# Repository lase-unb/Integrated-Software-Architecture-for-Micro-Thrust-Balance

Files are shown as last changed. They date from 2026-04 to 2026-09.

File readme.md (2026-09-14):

# Integrated Software Architecture for Micro-Thrust Balance

> Pipeline digital de quatro camadas para automação metrológica e tratamento de ruídos em bancadas de microempuxo 





---

## Visão Geral

Este repositório contém a arquitetura de software desenvolvida no **Laboratório de Sistemas Espaciais (LaSE)** da Universidade de Brasília (UnB) para caracterização precisa de sistemas de micropropulsão.

A arquitetura é estruturada em um **pipeline digital de quatro camadas** implementado em Python, integrando análise espectral (FFT), filtragem Butterworth de quinta ordem com fase zero, Filtro de Kalman sintonizado em Gêmeo Digital, gerenciamento metrológico de dados e interface Streamlit para telemetria e geração automatizada de relatórios PDF institucionais.

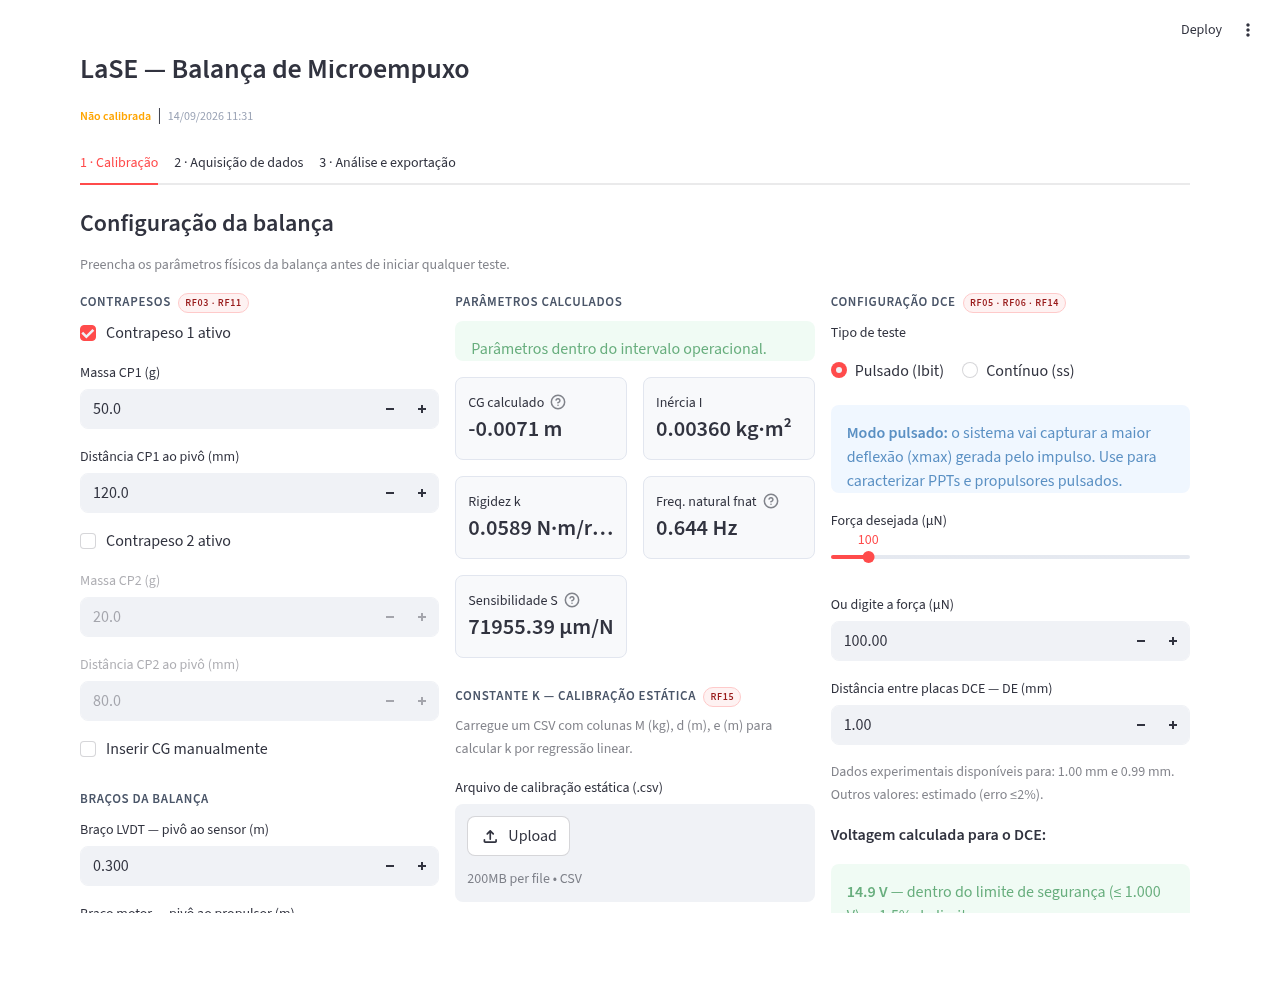
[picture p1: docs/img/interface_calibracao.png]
Aba de calibração da interface Streamlit


---

## Estrutura do Repositório

```
Integrated-Software-Architecture-for-Micro-Thrust-Balance/
│
├── Análises/                        # Análises experimentais anteriores (LaSE)
│   ├── data/                        # Dados brutos dos experimentos
│   ├── resultados/                  # Resultados processados
│   └── src/
│       ├── Hector/                  # Scripts de análise (H. Gessini)
│       └── ...                      # Scripts de análise física
│
├── calibration/                     # Camada 3 — calibração e gerenciamento
│   ├── physics/                     # Modelos físicos da balança
│   │   ├── centro_gravidade.m       # Cálculo do centro de gravidade
│   │   ├── carga_constante.m        # Análise de carga constante
│   │   ├── carga_constante_derivaTermica.m
│   │   ├── efeitojoule.py           # Modelagem efeito Joule
│   │   ├── efeitojoule_2.py
│   │   ├── eletroima_forca.py       # Força eletromagnética
│   │   ├── forca_eletroima.m
│   │   ├── graph_calibracao.m
│   │   ├── movimento_nucleo.py      # Dinâmica do núcleo
│   │   ├── plot_carga_cte.m
│   │   ├── relatorio_calibracao.py
│   │   ├── restricao_geo_forca.py
│   │   ├── superficie_calibracao.m
│   │   ├── 2_modo_vibracao.py       # Análise de modos de vibração
│   │   └── calibracao.py
│   ├── find_deflection.py           # Análise de deflexão + incerteza GUM (importado por interface/main.py)
│   ├── k_calculation.py             # Constante de rigidez efetiva k (importado por interface/main.py)
│   ├── dce_calibration.py           # Calibração in situ via DCE (simulada, sem hardware validado)
│   └── pendulum-dynamic.py          # Modelo dinâmico do pêndulo
│
├── signal_processing/               # Camadas 1 e 2 — FFT + DSP
│   ├── fn_calculation.py            # Análise espectral FFT + detecção de fn (importado por interface/main.py)
│   ├── processing.py                # Filtro Butterworth 5ª ordem + Kalman + conversão µm→mN
│   └── simulator.py                 # Gêmeo Digital do sistema dinâmico
│
├── interface/                       # Camada 4 — interface e relatórios
│   ├── main.py                      # Aplicação Streamlit (entry point — abas de calibração, aquisição e análise/exportação)
│   ├── live_plot.py                 # Telemetria em tempo real (50 ms)
│   ├── report_pdf.py                # Gerador de relatório PDF bilíngue PT/EN
│   └── web/                         # Interface web alternativa (HTML/CSS)
│       ├── index.html               # Dashboard
│       ├── calibracao.html          # Página de calibração
│       ├── analise.html             # Análise e exportação
│       └── style.css
│
├── hardware/                        # Aquisição de dados
│   ├── data_acquisition.py          # Interface serial USB com LVDT
│   └── dce_power_supply.py          # Driver SCPI/USB da fonte do DCE (real + simulado)
│
├── tools/                           # Scripts auxiliares
│   └── LVDT_Plot_V2.py              # Identificação de deslocamento máximo (importado por interface/main.py)
│
├── docs/                            # Documentação técnica
│   └── balanca.md                   # Especificações da balança
│
├── requirements.txt                 # Dependências Python
├── .gitignore
└── README.md
```

---

## Instalação

### Pré-requisitos

- Python 3.9+
- pip

### Passos

```bash
# Clone o repositório
git clone https://github.com/lase-unb/Integrated-Software-Architecture-for-Micro-Thrust-Balance.git
cd Integrated-Software-Architecture-for-Micro-Thrust-Balance

# Instale as dependências
pip install -r requirements.txt

# Execute a interface principal
streamlit run interface/main.py
```

---

## Pipeline de Quatro Camadas

| Camada | Módulo | Função |
|---|---|---|
| 1 — Análise Espectral | `signal_processing/fn_calculation.py` | FFT + janela Hanning → identificação de fn |
| 2 — DSP | `signal_processing/processing.py` | Butterworth 5ª ordem + filtfilt + Kalman |
| 2 — Gêmeo Digital | `signal_processing/simulator.py` | Modelo dinâmico para sintonização do Kalman |
| 3 — Calibração | `calibration/k_calculation.py` | Constante k, ajuste linear, R² |
| 3 — Metrologia | `calibration/find_deflection.py` | Deflexão + incerteza σ_d (GUM) |
| 3 — Pico de deflexão | `tools/LVDT_Plot_V2.py` | Identificação de xmax (regime pulsado) |
| 4 — Interface | `interface/main.py` | Streamlit: calibração, aquisição, análise (3 abas) |
| 4 — Telemetria | `interface/live_plot.py` | Monitoramento tempo real (50 ms) |
| 4 — Relatório | `interface/report_pdf.py` | PDF institucional bilíngue PT/EN, via ReportLab |

Os módulos das Camadas 1–3 (`fn_calculation.py`, `find_deflection.py`, `k_calculation.py`, `LVDT_Plot_V2.py`) funcionam tanto de forma independente (`python <script>.py`, para análise offline de um arquivo) quanto importados diretamente por `interface/main.py` — não há lógica duplicada entre o app e os scripts standalone.

---

## Guia de Módulos

Descrição do que cada arquivo da arquitetura faz e como ele se encaixa no pipeline. Não cobre `Análises/` (scripts históricos de experimentos anteriores do LaSE, fora da arquitetura de software mantida).

### `calibration/`

`find_deflection.py` calcula a deflexão (Δd) entre uma janela de baseline e uma janela de patamar, com incerteza combinada σ_c = √(σ₁²+σ₂²) (GUM). A função `calcular_deflexao()` é importada por `interface/main.py`, mas o script também roda sozinho (`python find_deflection.py arquivo.txt`) para uma análise offline com gráfico.

Rigidez efetiva k é assunto de dois módulos, dependendo da fonte de força usada na calibração. `k_calculation.py` faz isso a partir de massas conhecidas — regressão linear T(θ)=k·θ+a por mínimos quadrados, com R² pra validar o ajuste (`calibracao_estatica()`). `dce_calibration.py` faz o mesmo ajuste, mas trocando a massa pela força eletrostática do DCE (lei quadrática de placas paralelas, `forca_dce()`), varrendo voltagens e lendo a deflexão resultante em `calibrar_via_dce()`. Tem interlock de 1000V embutido, mas **só foi validado em simulação** até agora (`python dce_calibration.py`, com `FontePowerSupplySimulada`) — falta testar com a fonte/DCE/LVDT reais e ligar isso na interface Streamlit.

`pendulum-dynamic.py` ainda não tem implementação — só cabeçalho, reservado pras equações diferenciais da dinâmica do pêndulo (simples e 2º modo de vibração). E `physics/` guarda os scripts MATLAB/Python de modelagem física usados no dimensionamento da balança (efeito Joule, força eletromagnética, geometria do núcleo); não são importados pelo app, ficam como referência de cálculo.

### `signal_processing/`

`processing.py` é o núcleo de DSP do projeto e é importado por praticamente todo o resto (main.py, live_plot.py, fn_calculation.py, LVDT_Plot_V2.py). `apply_kalman_filter()` implementa o Filtro de Kalman linear de 2 estados (posição e velocidade) sintonizado pela frequência natural; `apply_lowpass_filter()` roda o Butterworth 5ª ordem fase-zero (`filtfilt`) seguido do Kalman; `convert_to_mn()` converte µm em mN; `calculate_metrics()` extrai bias, empuxo nominal e ruído RMS.

A frequência natural (fnat) sai de `fn_calculation.py`, via FFT (rfft) do sinal filtrado buscando o pico de maior magnitude — `calcular_fnat()`, importada por `interface/main.py` e também executável sozinha.

`simulator.py` é diferente dos outros: gera dados sintéticos de pêndulo amortecido (ruído + oscilação + degrau de empuxo) e escreve continuamente em `data.txt` respeitando o tempo real (`time.sleep`), pra testar `live_plot.py` sem hardware. Ninguém importa esse arquivo — `main.py` tem seu próprio gerador de simulação, em lote.

### `interface/`

`main.py` é o ponto de entrada da aplicação (`streamlit run interface/main.py`), com três abas: Calibração, Aquisição de dados e Análise/exportação. `report_pdf.py` gera o relatório PDF bilíngue PT/EN via ReportLab quando o botão "Gerar PDF" da aba 3 é clicado (`gerar_pdf()`). `live_plot.py` é uma ferramenta à parte — visualizador desktop standalone (matplotlib `FuncAnimation`, 50 ms) que lê um arquivo fixo via polling, não integrado ao app Streamlit. E `web/` é só um mockup estático em HTML/CSS/Chart.js, sem backend nenhum por trás.

### `hardware/`

`data_acquisition.py` lê a porta serial USB do condicionador do LVDT (baud rate 9600) e grava em `data.txt` no formato esperado pelos outros módulos. `dce_power_supply.py` é o par de classes usadas pela calibração via DCE: `RigolDP932U` fala SCPI de verdade com a fonte via PyVISA (não testada com hardware ainda), e `FontePowerSupplySimulada` imita a mesma interface sem precisar do equipamento.

### `tools/`

`LVDT_Plot_V2.py` identifica o xmax (maior deflexão absoluta) num sinal já filtrado — usado na análise do regime pulsado, exposto como `detectar_xmax()` e importado por `interface/main.py`.

---

## Publicação

**Arquitetura de Software Integrada para Automação Metrológica e Tratamento de Ruídos em Bancadas de Microempuxo**

Sessão 2 — Sustentabilidade, Educação, Ciência e Tecnologia | Formato: Presencial

**Autores:**
- Luana Carvalho de Almeida — 242004840@aluno.unb.br (UnB)
- Thamiris Thomazini Libard — 200043820@aluno.unb.br (UnB)
- Lui Txai Calvoso Habl — lui.habl@unb.br (UnB)
- Paolo Gessini (UnB)

**Palavras-chave:** micropropulsão · arquitetura de software modular · processamento digital de sinais · calibração eletrostática in situ · Gêmeo Digital

---

## Licença

[PolyForm Noncommercial 1.0.0](LICENSE) — uso, cópia, modificação e redistribuição livres para fins não comerciais (pesquisa, ensino, uso pessoal, organizações sem fins lucrativos). Uso comercial requer licenciamento separado com o LaSE.

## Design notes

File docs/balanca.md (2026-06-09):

<div align="center">

<br/>

**Micro-Thrust Balance — Signal Processing & Autonomous Calibration Pipeline**

*LaSE · Laboratory of Space Systems*

<br/>



[]()
[]()


<br/>

> A full signal processing, autonomous calibration, and data acquisition pipeline  
> for the micro-thrust balance used in small satellite propulsion testing at LaSE.

<br/>

---

</div>

## Overview

This repository contains the software infrastructure for operating the **LaSE Micro-Thrust Balance**, a precision torsional pendulum instrument used to characterize pulsed and continuous thrust from small satellite propulsion systems (PPTs and similar).

The pipeline covers three main layers:

- **Signal Filtering** — real-time noise filtering on LVDT sensor data
- **Autonomous Calibration** — automated static and dynamic calibration sequences (DCE-driven)
- **Interface** — web-based GUI for lab operators, designed for non-specialist use in isolated environments

All modules operate **100% offline** — no internet dependency at runtime — targeting deployment in vacuum chamber environments.

<br/>

---

## Repository Structure

```
microthrustpy/
│
├── filters/                   # Signal processing & noise filtering
│   ├── butterworth.py         #   Butterworth filter (order 5, cutoff 0.05·fnat)
│   ├── fft_analysis.py        #   FFT with Hanning window, 0.01 Hz resolution
│   └── steady_state.py        #   Steady-state detection (<0.1% variation threshold)
│
├── calibration/               # Autonomous calibration pipeline
│   ├── static_cal.py          #   Static calibration sequence
│   ├── dynamic_cal.py         #   Dynamic calibration (J, k, ω₀, S via FFT)
│   ├── dce_controller.py      #   DCE voltage control (<5 ms latency, ≤1000 V limit)
│   └── cg_calculator.py       #   Center-of-gravity computation from counterweight data
│
├── acquisition/               # Data acquisition
│   └── lvdt_reader.py         #   Real-time LVDT capture at 100 Hz (zero-packet-loss)
│
├── analysis/                  # Post-acquisition analysis
│   ├── pulsed_mode.py         #   xmax extraction from transient (first peak-valley)
│   ├── continuous_mode.py     #   Steady-state mean: xss/FE → sensitivity S
│   └── regression.py         #   Linear / least-squares curve fitting (R² > 0.99)
│
├── interface/                 # Web GUI (offline)
│   ├── app.py                 #   Main application entry point
│   ├── pages/                 #   Calibration, Acquisition, Analysis views
│   └── components/            #   Reusable UI components
│
├── reports/                   # Export engine
│   └── exporter.py            #   CSV (UTF-8) and PDF (ReportLab) generation
│
├── docs/                      # Documentation
│   └── requirements_spec.pdf  #   Full software requirements specification
│
├── tests/                     # Unit and integration tests
└── README.md
```

<br/>

---

## Key Features

### Signal Filtering
- Real-time noise reduction on LVDT displacement signals
- Butterworth low-pass filter (order 5, cutoff = `0.05 × fnat`)
- FFT analysis with Hanning window at 0.01 Hz resolution
- Automatic steady-state detection (variation threshold < 0.1%)
- Dashboard updates every **10 ms**; FFT processing < **1 s** for 1-minute signals

### Autonomous Calibration
- Full static + dynamic calibration sequences in < 30 min
- Computes: moment of inertia **J**, torsional stiffness **k**, natural frequency **ω₀**, and sensitivity **S**
- DCE voltage auto-calculation from target force input (precision: 0.1 V)
- Center-of-gravity computation from counterweight mass and position inputs
- Hard voltage limit: **≤ 1000 V** with software interlock, visual/audio alert, and incident logging
- Post-calibration recommendations based on threshold rules (e.g., hysteresis > 2%)

### Acquisition & Analysis
| Mode | Focus | Key Metric |
|---|---|---|
| **Pulsed (DCE)** | Transient regime | `xmax` — first peak-valley, resolution 0.01 μm |
| **Continuous (DCE)** | Steady-state regime | `xss` — mean after τ × 4 settling, σ < 0.01 μm |

- Supports N ≥ 10 repeated pulses with mean and standard deviation
- `xss / FE` → sensitivity S (μm/N or V/N), error < 1% vs. analytical
- FE lookup table from experimental curves; DE interpolation error ≤ 2%

### Interface
- Offline web application (no internet dependency)
- Pulsed / Continuous mode toggle with automatic parameter switching
- Real-time interactive plots (time domain + FFT) with zoom and pan
- Drag-and-drop layout, contextual tooltips, responsive in < 50 ms
- Automatic recalibration alert when mass or CG changes > 1%

### Reporting
- Export to **PDF** (ReportLab) and **CSV** (UTF-8)
- Includes: time/FFT graphs, calibration curves, parameter tables, uncertainty estimates, timestamps
- Download time < 10 s for 1 hour of data

<br/>

---

## Requirements

| Requirement | Value |
|---|---|
| Python | ≥ 3.10 |
| Network | Not required (fully offline) |
| Calibration error | < 1% (INMETRO/EURAMET standards) |
| Measurement repeatability | < 0.05 Ns |
| DCE control latency | < 5 ms |
| Dashboard refresh | 10 ms |
| Max DCE voltage | 1000 V (hard limit) |
| MTBF | ≥ 99.9% over 8 h operation |

<br/>

---

## Getting Started

```bash
# Clone the repository
git clone https://github.com/your-org/microthrustpy.git
cd microthrustpy

# Install dependencies
pip install -r requirements.txt

# Run the interface
python interface/app.py
```

> **Note:** The system is designed for isolated lab environments. No external network calls are made at any point during operation.

<br/>

---

## Requirements Specification

The full software requirements document is available at [`docs/requirements_spec.pdf`](docs/requirements_spec.pdf).

A summary of the requirement matrix:

| ID | Title | Priority | Status |
|----|---|---|---|
| RNF01 | Offline Operation | Must Have | Proposed |
| RF01 | Full Calibration, Acquisition & Analysis Coverage | Must Have | Proposed |
| RF02 | Statistics for Pulsed and Continuous Loads | Must Have | Proposed |
| RF03 | Counterweight & Distance Input for Calibration | Must Have | Proposed |
| RF05 | DCE Force Magnitude Input | Must Have | Proposed |
| RF06 | Automatic DCE Voltage Calculation | Must Have | Proposed |
| RF07 | Steady-State Acquisition (Continuous DCE) | Must Have | Proposed |
| RF08 | Peak Amplitude Analysis (Pulsed DCE) | Must Have | Proposed |
| RF09 | Known-Input Consideration (Continuous DCE) | Must Have | Proposed |
| RF10 | Real-Time Curve Generation | Must Have | Proposed |
| RF13 | Real-Time LVDT Acquisition | Must Have | Proposed |
| RF14 | DCE Voltage Safety Limit (≤ 1000 V) | Must Have | Proposed |
| RF15 | Automated Static/Dynamic Calibration Sequences | Must Have | Proposed |
| RNF02 | Real-Time Performance | Must Have | Proposed |
| RI01 | Time Domain + FFT Visualization | Should Have | Proposed |
| RF16 | CSV/PDF Report Export | Should Have | Proposed |
| RNF03 | Measurement Precision & Reliability | Should Have | Proposed |
| RI02 | Pulsed / Continuous Mode Selection | Must Have | Proposed |
| RF04 | Post-Calibration Recommendations | Could Have | Proposed |
| RF11 | Automatic Center-of-Gravity Calculation | Could Have | Proposed |
| RF12 | Recalibration Reminder on Mass/CG Change | Could Have | Proposed |

<br/>

---

## Instrument Context

The **LaSE Micro-Thrust Balance** is a torsional pendulum designed to measure thrust forces in the range of **10 μN – 1 mN**, used for characterizing pulsed plasma thrusters (PPTs) and similar low-thrust propulsion systems for small satellites.

Key physical parameters:
- Sensor: **LVDT** (Linear Variable Differential Transformer)
- Excitation: **DCE** (Dynamic Capacitive Excitation), U ≤ 1000 V
- Calibration modes: static (sensitivity S) and dynamic (natural frequency ω₀)
- Operating environment: vacuum chamber (isolated, no network)

<br/>

---

## Contributing

This project is developed within the LaSE research group. For contribution guidelines, please refer to [`CONTRIBUTING.md`](CONTRIBUTING.md).

<br/>

---

## License

MIT License — see [`LICENSE`](LICENSE) for details.

<br/>

<div align="center">

---

*LaSE · Laboratory of Space Systems*  
*Developed for the Micro-Thrust Balance Project*

</div>

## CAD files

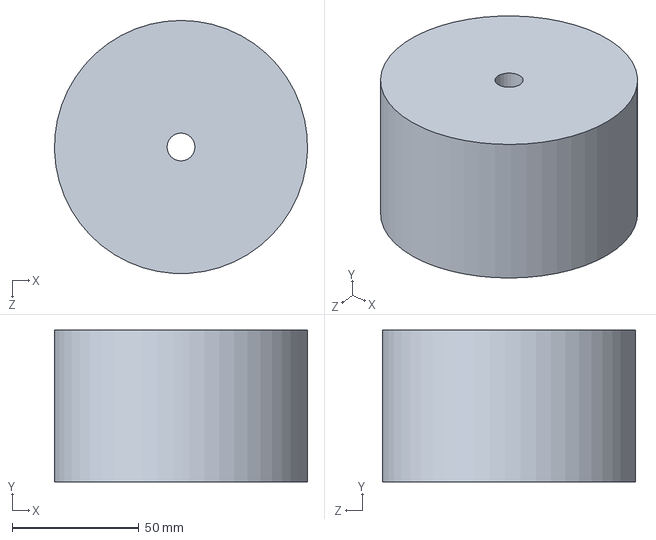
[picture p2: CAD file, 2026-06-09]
Análises/data/CG_CAD/CW_MAIOR.SLDPRT
100.0 x 60.0 x 100.0 mm

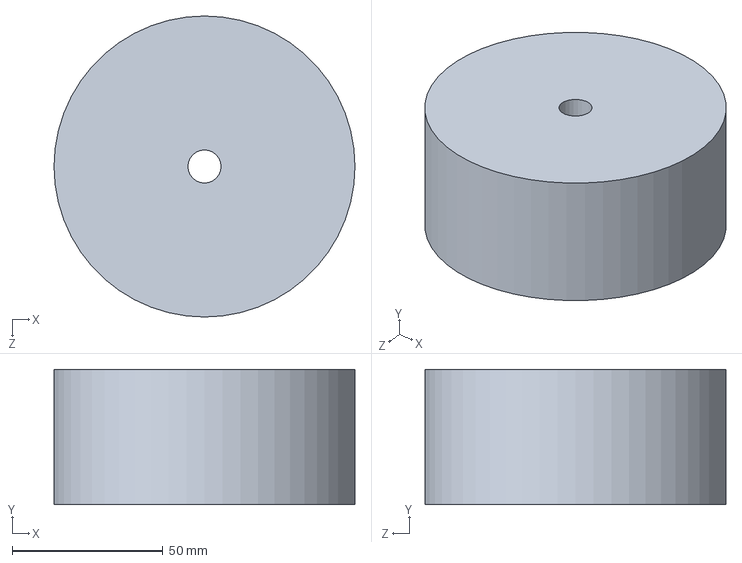
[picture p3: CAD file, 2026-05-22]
Análises/data/CG_CAD/CW_1kg.SLDPRT
100.0 x 45.0 x 100.0 mm

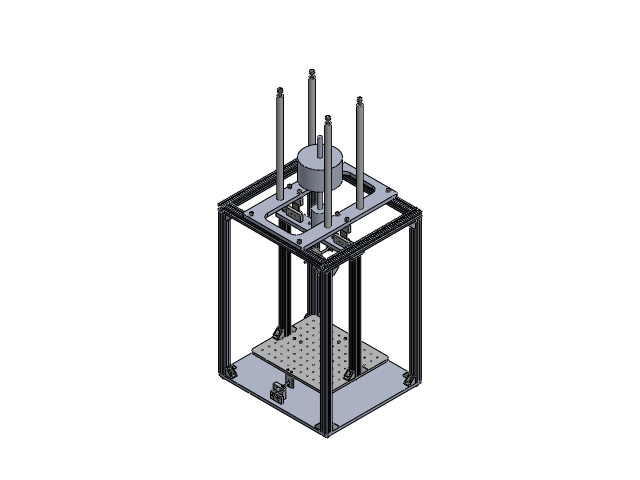
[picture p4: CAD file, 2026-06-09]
Análises/data/CG_CAD/0.Thrust_Balance_cg_y.SLDASM
TB_MainBeam-1
Blade_Spring-1 x 2
Spring_attachement-1 x 4
Spring_Clamp-1 x 4
profile_W20_L325-1 x 2
TB_Bottom_Plate-1
TB_M10_Rod-1
TB_Pdlm_Stop-1
TB_Horiz_Balance-1
TB_M5_Rod-1
TB_LVDT_Core_Plate-1
LVDT_Core-1
TB_1-72_Rod-1
TB_Counterweight_Arm-1
TB_Copper_Brake-1
TB_Calib_Plate-1
TB_Horiz_Counterweight-1
Bracket_Kit-1 x 20
TB_Calib_Pos_V2-1
CHC_M4x12-1 x 10
CHC_M3x16-1 x 5
CHC_M4x16-1 x 4
Washer_M4_ISO-7089-1 x 6
Washer_M6_ISO-7089-1 x 16
CHC_M6x20-1 x 16
Nut_M5_ISO-4032-1 x 2
CHC_M3x14-1 x 15
Pin_D3x10_M6-1 x 18
CHC_M5x16-1 x 12
Washer_M5_ISO-7089-1 x 12
Washer_M2_ISO-7089-1 x 3
CHC_M2x10-1 x 4
profile_W20_L300-1 x 4
TB_Top_Beam-1
profile_W20_L440-1 x 4
TB_Stand_Hanging_Rods-1 x 4
Porca Martelo Canal 6 - M5-1 x 4
TB_Base_Plate-1
LVDT_Body-1
LVDT_Body_Clamp-1
TB_Pdlm_Bumper-1
LVDT_Body_Clamp_Attach-1
TB_Electromagnet-1 x 2
TB_Electromagnet_Plate-1 x 2
Nut_M3_ISO-4032-1 x 2
Washer_M3_ISO-7089-1 x 11
CW_MAIOR

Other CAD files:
Análises/data/CG_CAD/TB_MainBeam-1.SLDPRT
Análises/data/CG_CAD/TB_Stand-1.SLDASM
Análises/data/CG_CAD/TB_Pendulum-1.SLDASM
Análises/data/CG_CAD/TB_Base-1.SLDASM
Análises/data/CG_CAD/profile_W20_L440-1.SLDPRT
Análises/data/CG_CAD/TB_Base_Plate-1.SLDPRT
Análises/data/CG_CAD/TB_M10_Rod-1.SLDPRT
Análises/data/CG_CAD/TB_Top_Beam-1.SLDPRT
Análises/data/CG_CAD/TB_Counterweight_Arm-1.SLDPRT
Análises/data/CG_CAD/TB_Stand_Hanging_Rods-1.SLDPRT
Análises/data/CG_CAD/TB_Bottom_Plate-1.SLDPRT
Análises/data/CG_CAD/profile_W20_L300-1.SLDPRT
Análises/data/CG_CAD/TB_Electromagnet_Plate-1.SLDPRT
Análises/data/CG_CAD/CHC_M6x20-1.SLDPRT
Análises/data/CG_CAD/TB_M5_Rod-1.SLDPRT
Análises/data/CG_CAD/0.Thrust_Balance_cg_y.x_t
Análises/data/CG_CAD/Blade_Spring-1.SLDPRT
Análises/data/CG_CAD/Bracket_Kit-1.SLDPRT
Análises/data/CG_CAD/CHC_M2x10-1.SLDPRT
Análises/data/CG_CAD/CHC_M3x14-1.SLDPRT
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

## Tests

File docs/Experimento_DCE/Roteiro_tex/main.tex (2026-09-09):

\documentclass[12pt,a4paper,twoside]{article}

% are used to comment out text

%------------------------------------------------------------------------------------------------------------
%EDIT THESE FIELDS WITH YOUR DETAILS
%------------------------------------------------------------------------------------------------------------
\newcommand{\studentname}{}
%\newcommand{\studentnumber}{}
\title{Experimento de Validação do Dispositivo de Calibração Eletrostática (DCE) \\ Roteiro}
\newcommand{\tutor}{}
%\newcommand{\labgroup}{}
\newcommand{\labdate}{July 2026}
\newcommand{\reportdate}{XX Julho de 2026}
%------------------------------------------------------------------------------------------------------------

%------------------------------------------------------------------------------------------------------------
%PACKAGES. PACKAGES ARE USED TO EXTEND THE FUNCTIONALITY OF LATEX. YOU SHOULDN'T
%NEED ANY MORE, SPEND YOUR TIME ON THE CONTENT!
%------------------------------------------------------------------------------------------------------------

\usepackage[a4paper,left=25mm,right=25mm,bottom=25mm,top=25mm]{geometry}
\usepackage{fancyhdr}
\usepackage{subfigure}
\usepackage{graphicx}
\usepackage{cleveref}
\usepackage{booktabs}
\usepackage[british]{babel}
\usepackage[square,comma,numbers,sort&compress]{natbib}
\usepackage{csvsimple}
\usepackage{graphicx}
\usepackage{pgfplotstable}
\usepackage{gensymb}
\usepackage{array}
\usepackage{multirow}
\usepackage{url}
\pgfplotsset{compat=1.9}% supress warning
\begin{document}

%------------------------------------------------------------------------------------------------------------

%------------------------------------------------------------------------------------------------------------
%DO NOT EDIT THESE FIELDS
%------------------------------------------------------------------------------------------------------------
\setlength{\parindent}{0em}
\setlength{\parskip}{0.5em}
%\author{\studentname \\ Orientação: \tutor.}
\date{Data do Relatório: \reportdate.}

\pagestyle{fancy}
\fancyhead{}
%\fancyhead[C]{\studentname~\studentnumber}
\fancyfoot{}
\fancyfoot[C]{\thepage}
\renewcommand{\headrulewidth}{0pt}
\renewcommand{\footrulewidth}{0pt}

\renewcommand\bibname{Referências}

%------------------------------------------------------------------------------------------------------------

\maketitle

%------------------------------------------------------------------------------------------------------------
% REPORT BEGINS HERE
%------------------------------------------------------------------------------------------------------------
%%%%%%%%%%%%%%%%
\section{Protocolos de Segurança e EPIs}

Antes de iniciar qualquer etapa prática, os procedimentos de segurança contra Alta Tensão devem ser estritamente seguidos.

\subsection*{Equipamentos de Proteção Individual (EPIs):}
\begin{itemize}
    \item \textbf{Luvas Isolantes (Classe 0):} Específicas para trabalhos elétricos, certificadas para suportar até 1000\,V AC ou 1500\,V DC. Devem ser usadas com luvas de vaqueta por cima para proteção mecânica.
    \item \textbf{Calçado de Segurança com Isolamento Elétrico:} Calçado fechado sem componentes metálicos.
    \item \textbf{Óculos de Segurança:} Essencial caso ocorra a ruptura dielétrica do ar (centelha) entre as placas do DCE, o que pode ejetar pequenas partículas de alumínio.
    \item \textbf{Jaleco/Vestimenta 100\% Algodão:} Materiais sintéticos derretem na pele em caso de arco elétrico.
\end{itemize}

\subsection*{Equipamentos de Proteção Coletiva (EPCs) e Cuidados Especiais:}
\begin{itemize}
    \item \textbf{Tapete Isolante de Borracha:} Deve estar posicionado no chão, onde o operador da fonte HV ficará em pé.
    \item \textbf{Bastão de Aterramento (Bastão de Descarga):} Essencial para o pós-teste. O DCE atua como um capacitor e armazena carga. Mesmo com a fonte desligada, as placas podem reter carga suficiente para causar um choque severo.
    \item \textbf{Sinalização e Isolamento:} A área ao redor da balança deve estar demarcada com faixas de ``Perigo: Alta Tensão''.
    \item \textbf{Prevenção de Ruptura Dielétrica:} Centelhas aparecem na extremidade de condutores quando o campo elétrico provoca a ruptura dielétrica do ar. A 1000\,V em pressão atmosférica, se as placas estiverem muito coladas (ex: menor que 0,5\,mm), uma centelha pode ocorrer, podendo fechar um curto-circuito na sua fonte. Garanta que a distância (\textit{gap}) seja segura.
\end{itemize}

\section{Preparação do Sistema (Com a fonte totalmente desligada)}

\begin{enumerate}
    \item \textbf{Montagem Mecânica:} Fixe um disco de alumínio no braço móvel do pêndulo e o outro disco no suporte fixo da base.
    \item \textbf{Alinhamento:} Utilize um paquímetro ou micrômetro para ajustar a distância $D_E$ (entre-ferro) inicial entre os discos de alumínio. Garanta que as placas estejam perfeitamente paralelas.
    \item \textbf{Cabeamento:} Conecte os cabos de alta tensão da fonte de tensão Magna-Power aos eletrodos do DCE. Garanta que os cabos estejam fixos e não interfiram excessivamente na rigidez mecânica (constante elástica) do pêndulo.
    \item \textbf{Aterramento:} Verifique se o chassi da balança e a carcaça da fonte de tensão estão devidamente aterrados na malha do laboratório.
\end{enumerate}

\section{Execução do Experimento (Teste Estático em Atmosfera)}

Este procedimento descreve a calibração primária do DCE, onde a constante $K_{dce}$ será validada na pressão atmosférica, antes de ir para o vácuo.

\begin{enumerate}
    \item \textbf{Afastamento:} Todos os envolvidos devem se afastar da balança e ficar atrás de uma barreira ou a uma distância segura, sobre o tapete isolante.
    \item \textbf{Ligação do Sistema:} Ligue a alimentação geral do laboratório e ligue a fonte Magna-Power, garantindo que o controle de tensão esteja zerado (0\,V) e o limite de corrente (corrente de corte) configurado para um valor mínimo de segurança (ex: 10\,mA, pois o DCE não consome corrente em estado estacionário por ser um capacitor; se puxar corrente, há um curto ou fuga).
    \item \textbf{Degraus de Tensão:} Aumente a tensão para 100\,V. \\
    \textit{Atenção:} Ao aplicar a tensão contínua, o pêndulo será atraído e passará a oscilar em torno de uma nova coordenada de equilíbrio.
    \item \textbf{Regime Estacionário:} É estritamente necessário aguardar a completa atenuação do regime transiente (oscilações) até que o sistema atinja o regime estacionário para efetuar a leitura do deslocamento. Aguardar 3 minutos para garantir que as oscilações tenham cessado.
    \item \textbf{Registro de Dados:} Salve o gráfico de deslocamento do pêndulo (eixo Y) versus tempo (eixo X) usando o software de aquisição. Anote o valor do deslocamento final (posição de equilíbrio) e a tensão aplicada obtido pelo script para cada caso.
    \item \textbf{Repetitibilidade}: Repita o passo de 100\,V mais 4 vezes para garantir a repetibilidade dos dados.
    \item \textbf{Progressão:} Repita os passos de aumento de tensão em incrementos de 100\,V (100\,V, 200\,V, 300\,V, 400\,V, 500\,V, 600\,V, 700\,V, 800\,V e 1000\,V). Espere o regime estacionário e anote os dados em cada degrau.
\end{enumerate}

\section{Desenergização e Coleta de Dados}

\begin{enumerate}
    \item \textbf{Redução de Tensão:} No painel da fonte Magna-Power, reduza gradativamente a tensão de 1000\,V de volta para 0\,V.
    \item \textbf{Desligamento Geral:} Desligue o botão de \textit{Output} da fonte e, em seguida, a chave geral da fonte.
    \item \textbf{Procedimento de Descarga (Crítico):} 
    \begin{itemize}
        \item Coloque as Luvas Isolantes Classe 0.
        \item Pegue o bastão de aterramento.
        \item Encoste a ponta do bastão simultaneamente nos terminais de ambas as placas do DCE (ou faça o aterramento de uma placa contra a outra) para curtocircuitar o capacitor e garantir que toda a energia potencial armazenada no campo elétrico seja dissipada.
        \item Mantenha o bastão no local por cerca de 5 segundos.
    \end{itemize}
    \item \textbf{Análise de Dados:}
    \begin{itemize}
        \item Organize os dados coletados em um gráfico. No eixo X, coloque o quadrado da tensão aplicada ($V^2$) e no eixo Y, o deslocamento medido ou a força calculada.
        \item A relação deverá ser estritamente linear, comprovando a equação teórica da força do capacitor de placas paralelas ($F_c \propto V^2/d^2$). A inclinação desta reta fornecerá a constante experimental do seu DCE.
    \end{itemize}
\end{enumerate}

%%%%%%%%%%%%%%%%
\section{Resultados}

%%%%%%%%%%%%%%%%
\section{Conclusões}

\newpage
\bibliographystyle{unsrtnat}
%\bibliography{refs}

\end{document}

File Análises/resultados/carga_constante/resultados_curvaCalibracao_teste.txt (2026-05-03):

Nome_Arquivo	Forca_Equivalente_uN	Deslocamento_script_um	Desvio_Padrao_um
P1_d1.txt	167,19602050612247	1,5257615127211728	0,0847188425542229
P1_d1_2.txt	167,19602050612247	1,423237273916354	0,10081185710970245
P1_d1_3.txt	167,19602050612247	1,7979466146174659	0,1320189710717909
P1_d1_4.txt	167,19602050612247	1,803923883389686	0,07340159617379274
P1_d1_5.txt	167,19602050612247	2,02775885370329	0,06566519335507003
P2_d1.txt	219,76349570612243	1,9977216844821206	0,09998581312962104
P2_d1_2.txt	219,76349570612243	2,185506640054078	0,057896090001982654
P3_d1.txt	324,3693912816326	2,9960000375033786	0,07785437182987949
P3_d1_4.txt	324,3693912816326	3,936914121682552	0,05213388109193224
P3_d1_5.txt	324,3693912816326	3,975132900426125	0,06678971680006586
P3_d1_2.txt	324,3693912816326	2,401573254417534	0,06568608605840764
P3_d1_3.txt	324,3693912816326	3,631233662864524	0,07050381880791896
P1_d3_2.txt	470,08736200272114	3,5189739630420265	0,12415216248666912
P1_d3_1.txt	470,08736200272114	3,128133765737345	0,1001355470794617
P4_d1_2.txt	481,8954652734694	4,728323381513613	0,09218229028524261
P4_d1_1.txt	481,8954652734694	5,847511926572043	0,5436711886457491
P5_d1_3.txt	486,3336474122449	6,1015968327933585	0,0938840737455045
P5_d1_4.txt	486,3336474122449	5,837186548189514	0,10796600635575272
P5_d1.txt	486,3336474122449	4,471582365708118	0,06322730074100216
P5_d1_2.txt	486,3336474122449	5,0236660193102765	0,08652542680489857
P5_d1_5.txt	486,3336474122449	5,542642240444724	0,0871379726897231
P6_d1.txt	634,909877289796	5,803216918252013	0,0589699351167432
P6_d1_2.txt	634,909877289796	6,101860402085155	0,18148414246878633
P7_d1.txt	808,3663798857143	7,245674717473794	0,10894271299596024
P7_d1_4.txt	808,3663798857143	9,326338333507962	0,1511031401914969
P7_d1_5.txt	808,3663798857143	9,900776901035588	0,13118236012623757
P7_d1_2.txt	808,3663798857143	7,651419551723982	0,10690424291529421
P7_d1_3.txt	808,3663798857143	9,783391551319387	0,09111040837898571
P3_d3_2.txt	911,9951001251701	5,871157888343973	0,0955963767657098
P3_d3_1.txt	911,9951001251701	5,362589192377063	0,1448660306277207

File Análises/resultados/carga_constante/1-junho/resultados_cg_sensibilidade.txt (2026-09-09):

Posição do Centro de Gravidade (Y): -0.0469 m (pivô como referencial)
Sensibilidade: 0.1347 m/N
O CG está abaixo do pivô (Equilíbrio Estável).

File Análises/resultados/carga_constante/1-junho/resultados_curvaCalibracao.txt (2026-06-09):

Nome_Arquivo	Forca_Equivalente_uN	Deslocamento_script_um	Desvio_Padrao_um
P0_d1_1.txt	38,76796186122449	2,403502692934687	0,43667310197107273
P0_d1_2.txt	38,76796186122449	2,513435426002636	0,40176564468827736
P0_d1_3.txt	38,76796186122449	1,8276263647902447	0,40053585945937875
P0_d1_4.txt	38,76796186122449	1,9686197474111644	0,22737244951449148
P0_d2_1.txt	73,88386934421769	3,0038958834640654	0,2563268368378421
P0_d2_2.txt	73,88386934421769	2,8154681605823972	0,20710931755053044
P0_d2_3.txt	73,88386934421769	2,69438044799963	0,3429057070252555
P0_d3_1.txt	108,99977682721091	3,828803228090366	0,22083267520907957
P0_d3_2.txt	108,99977682721091	3,5587853240005654	0,2189450045682989
P0_d3_3.txt	108,99977682721091	3,6734036542266644	0,20255503737436872
P1_d1_1.txt	167,19602050612247	8,633472084695583	0,30189131461536073
P1_d1_2.txt	167,19602050612247	8,62670291489669	0,1741975221053034
P1_d1_3.txt	167,19602050612247	9,16807300039471	0,2380926945382513
P2_d1_3.txt	219,76349570612243	11,798404707483801	0,279440604848147
P2_d1_2.txt	219,76349570612243	11,899051910254222	0,49500553293683913
P2_d1_1.txt	219,76349570612243	12,218874907695508	0,15754191354837033
P1_d2_3.txt	318,6416912544218	13,283066393146322	0,2644982409625571
P1_d2_2.txt	318,6416912544218	12,914548909380583	0,21801517380257193
P1_d2_1.txt	318,6416912544218	13,648610378738946	0,31058839217420736
P3_d1_2.txt	324,3693912816326	15,705750710753284	0,3393701628308525
P3_d1_3.txt	324,3693912816326	17,93979893484458	0,29127607810198525
P3_d1_1.txt	324,3693912816326	17,077403610058816	0,3871110575263661
P2_d2_2.txt	418,8246331210885	17,146525562076825	0,28788091744504263
P2_d2_1.txt	418,8246331210885	23,835531064213125	0,5625875705722148
P2_d2_3.txt	418,8246331210885	17,967163579079365	0,3007330341842944
P1_d3_2.txt	470,08736200272114	18,24113165945115	0,15590258690300465
P1_d3_3.txt	470,08736200272114	17,04741482104593	0,3459095156472804
P1_d3_1.txt	470,08736200272114	16,664189660936295	0,24938925533366413
P4_d1_3.txt	481,8954652734694	19,672867488648333	0,42484625618899774
P4_d1_1.txt	481,8954652734694	19,998665261036592	0,20320758230025293
P4_d1_2.txt	481,8954652734694	19,81561104501081	0,29726348344539777
P2_d3_3.txt	617,8857705360545	22,17218777100156	0,24148562100873341
P2_d3_2.txt	617,8857705360545	23,192170732084094	0,27223730692621206
P2_d3_1.txt	617,8857705360545	23,098995132296608	0,3994763981536598
P3_d2_1.txt	618,1822457034013	25,663902881555966	0,2573513778796887
P3_d2_2.txt	618,1822457034013	25,260723184498	0,2480756301547863
P3_d2_3.txt	618,1822457034013	25,282917237628883	0,32691706186873737
P6_d1_1.txt	634,909877289796	26,99153604192403	0,44793860068120384
P6_d1_2.txt	634,909877289796	25,95334424086613	0,3550077950893278
P6_d1_3.txt	634,909877289796	27,042483362345255	0,43259927312465984
P3_d3_3.txt	911,9951001251701	43,54338783432895	0,6489077211611296
P3_d3_2.txt	911,9951001251701	43,202471960031446	0,7153313834715435
P3_d3_1.txt	911,9951001251701	42,730582988542515	0,7373516418838583
P4_d2_1.txt	918,3949809197279	29,907008837138807	0,3742552502023089
P4_d2_3.txt	918,3949809197279	30,59392540078414	0,5479790027742987
P4_d2_2.txt	918,3949809197279	30,164727678952286	0,3262280679177168
P4_d3_3.txt	1354,8944965659866	40,232529444594526	0,4231248164377877
P4_d3_1.txt	1354,8944965659866	38,95183580052546	0,43931733716292914
P4_d3_2.txt	1354,8944965659866	39,26437231190002	0,2961059232581944
P7_d3_1.txt	2272,798227504762	64,61636094692994	0,6670930592581455
P7_d3_2.txt	2272,798227504762	63,41490839695941	0,5365559092649418
P7_d3_3.txt	2272,798227504762	60,94000064204092	0,6049461692586704

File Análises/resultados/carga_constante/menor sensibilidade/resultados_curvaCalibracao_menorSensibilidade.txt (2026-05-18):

Nome_Arquivo	Forca_Equivalente_uN	Deslocamento_script_um	Desvio_Padrao_um
P1_d1.txt	167,19602050612247	0,47878218626424274	0,055879953376245746
P1_d1_1.txt	167,19602050612247	1,5818780849747145	0,11333580551979579
P1_d1_2.txt	167,19602050612247	1,5793800781383687	0,0719010975496919
P1_d1_3.txt	167,19602050612247	1,4981831345914713	0,07981482153715336
P1_d1_4.txt	167,19602050612247	1,5660638871838728	0,10453777712424396
P1_d1_5.txt	167,19602050612247	1,7841840487733356	0,08979430690193721
P2_d2_1.txt	418,8246331210885	1,3578447420443047	0,14730095252805597
P2_d2_2.txt	418,8246331210885	3,0494928129613026	0,08875763320143154
P2_d2_3.txt	418,8246331210885	3,0024541156654068	0,11801174244513023
P2_d2_4.txt	418,8246331210885	3,2650759268464578	0,08741940829115541
P2_d2_5.txt	418,8246331210885	3,3619535592758094	0,06489465646632887
P3_d2.txt	618,1822457034013	1,8185122365609574	0,04539462346158758
P3_d2_2.txt	618,1822457034013	4,361837123939637	0,11640431508878883
P3_d2_3.txt	618,1822457034013	4,459209873727531	0,056662684484395556
P3_d2_5.txt	618,1822457034013	4,507825470218898	0,09609242090001395
P3_d3.txt	911,9951001251701	1,8418879778596315	0,0769171353548244
P4_d2_1.txt	918,3949809197279	7,153163045546448	0,09901791051584206
P4_d2_2.txt	918,3949809197279	7,067028188321593	0,1140393442872182
P4_d2_3.txt	918,3949809197279	7,196669646190167	0,13125996234814097
P4_d2_4.txt	918,3949809197279	7,178282280808455	0,16110967770165932
P4_d2_5.txt	918,3949809197279	7,210179371709199	0,16114993955344462
P5_d2_1.txt	926,8532555755103	7,158757897235225	0,07460354957214625
P5_d2_2.txt	926,8532555755103	7,028167764212013	0,1313197535968486
P5_d2_3.txt	926,8532555755103	6,99492570207693	0,1162992181570608
P5_d2_4.txt	926,8532555755103	7,2631409297788405	0,14425910815698229
P5_d2_5.txt	926,8532555755103	16,736394583542843	0,9197028427221509
P6_d2_1.txt	1210,0094038204084	9,234831551698488	0,11471240257551671
P6_d2_2.txt	1210,0094038204084	9,218782137449924	0,13110807308880087
P6_d2_3.txt	1210,0094038204084	10,406251782680021	0,14752876855436178
P6_d2_4.txt	1210,0094038204084	9,403541682541846	0,15566310256976884
P6_d2_5.txt	1210,0094038204084	9,333564505606386	0,12466646282792615
P7_d2_1.txt	1540,582303695238	11,884425641374225	0,14031483151816757
P7_d2_2.txt	1540,582303695238	11,696264833446035	0,11425747959846315
P7_d2_3.txt	1540,582303695238	11,686408191952774	0,14290674998989825
P7_d2_4.txt	1540,582303695238	12,32370200716419	0,2530004266156466
P7_d2_5.txt	1540,582303695238	11,550894638408451	0,17319437271619498
P7_d3.txt	2272,798227504762	6,690188939643546	0,054465380402743145
P7_d3_1.txt	2272,798227504762	15,404384982754294	0,14404906091157466
P7_d3_2.txt	2272,798227504762	14,946613142097284	0,12623910226958565
P7_d3_3.txt	2272,798227504762	15,749181115765417	0,14650972393381406
P7_d3_4.txt	2272,798227504762	15,436342889169918	0,2010066597902286
P7_d3_5.txt	2272,798227504762	15,236212053076015	0,14033213333560143

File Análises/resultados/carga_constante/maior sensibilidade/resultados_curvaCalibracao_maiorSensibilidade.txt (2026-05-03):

Nome_Arquivo	Forca_Equivalente_uN	Deslocamento_script_um	Desvio_Padrao_um
P1_d1.txt	167,19602050612247	2,650227953699916	0,11369586416679983
P1_d1_2.txt	167,19602050612247	3,34896717491921	0,11536284545163966
P1_d1_3.txt	167,19602050612247	3,445847660269667	0,06183247177552868
P1_d1_4.txt	167,19602050612247	3,330813480413589	0,08935715740704048
P1_d1_5.txt	167,19602050612247	3,3556346174619165	0,11619841108709628
P2_d2.txt	418,8246331210885	4,888385989627983	0,09344585163820131
P2_d2_2.txt	418,8246331210885	6,979409327518368	0,09868014687908253
P2_d2_3.txt	418,8246331210885	6,529744182431756	0,16377341655803862
P2_d2_4.txt	418,8246331210885	6,945556798820064	0,1698330320954138
P2_d2_5.txt	418,8246331210885	6,530774881494217	0,11288179977680181
P3_d2.txt	618,1822457034013	7,25647498058627	0,08465544417877831
P3_d2_2.txt	618,1822457034013	9,426835728325266	0,1825144586890916
P3_d2_3.txt	618,1822457034013	9,667968186343607	0,09574365001194722
P3_d2_4.txt	618,1822457034013	9,34651183823172	0,1613525604756109
P3_d2_5.txt	618,1822457034013	9,887503991114475	0,15032734544177598
P4_d2.txt	918,3949809197279	11,011556418605776	0,1369748078489766
P4_d2_2.txt	918,3949809197279	14,53038370141093	0,16400071495941096
P4_d2_3.txt	918,3949809197279	14,435607446278764	0,18255603862152064
P4_d2_4.txt	918,3949809197279	13,972350979984485	0,20592636157540814
P4_d2_5.txt	918,3949809197279	14,027645261003537	0,30000244892011524

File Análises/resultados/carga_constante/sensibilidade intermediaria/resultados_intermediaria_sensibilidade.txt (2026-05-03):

Posição do Centro de Gravidade (Y): -0.3131 m (pivô como referencial)
Sensibilidade: 0.0582 m/N
O CG está abaixo do pivô (Equilíbrio Estável).

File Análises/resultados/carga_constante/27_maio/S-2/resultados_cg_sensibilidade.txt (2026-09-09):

Posição do Centro de Gravidade (Y): -0.1245 m (pivô como referencial)
Sensibilidade: 0.0507 m/N
O CG está abaixo do pivô (Equilíbrio Estável).

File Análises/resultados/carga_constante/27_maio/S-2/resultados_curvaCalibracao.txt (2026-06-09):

Nome_Arquivo	Forca_Equivalente_uN	Deslocamento_script_um	Desvio_Padrao_um
P0_d1_1.txt	38,76796186122449	2,3770671814726114	0,41298512878606236
P0_d1_2.txt	38,76796186122449	1,8979533627479128	0,21600789870710743
P0_d1_3.txt	38,76796186122449	1,7956791388844096	0,15958287152845838
P0_d2_1.txt	73,88386934421769	2,885675281544652	0,22403704035429262
P0_d2_2.txt	73,88386934421769	2,3405007331176497	0,29312069220879483
P0_d2_3.txt	73,88386934421769	3,0024358183577284	0,1911609123772735
P0_d3_1.txt	108,99977682721091	3,7707123324567773	0,24371301570274165
P0_d3_2.txt	108,99977682721091	3,6699246796895224	0,14135390958525493
P0_d3_3.txt	108,99977682721091	3,860000871756685	0,18771475627141385
P1_d1_1.txt	167,19602050612247	7,919291797930228	0,4221992488206818
P1_d1_2.txt	167,19602050612247	7,969240676416391	0,39218302826884843
P1_d1_3.txt	167,19602050612247	9,745136744301547	0,4002467869174715
P2_d1_1.txt	219,76349570612243	11,698118147852739	0,2589473831201187
P2_d1_3.txt	219,76349570612243	11,694343985673243	0,35016799776061386
P2_d1_2.txt	219,76349570612243	11,645438693736168	0,29535804424338447
P1_d2_1.txt	318,6416912544218	14,208650858221048	0,4648936013887597
P1_d2_2.txt	318,6416912544218	12,232408763341216	0,2674834400168182
P1_d2_3.txt	318,6416912544218	12,508177186345911	0,3365948979798168
P3_d1_2.txt	324,3693912816326	17,155877044361347	0,3463698851754739
P3_d1_1.txt	324,3693912816326	17,47882044002769	0,3172184160883317
P3_d1_3.txt	324,3693912816326	16,983759629390804	0,4970740743888781
P2_d2_3.txt	418,8246331210885	15,841091839200054	0,3183205389351141
P2_d2_2.txt	418,8246331210885	16,212787606190837	0,31062478334147126
P2_d2_1.txt	418,8246331210885	16,168605911760466	0,33681287078302746
P1_d3_1.txt	470,08736200272114	16,990696911317727	0,29880045426410995
P1_d3_2.txt	470,08736200272114	17,056571676376016	0,31181668573730625
P1_d3_3.txt	470,08736200272114	17,33432840682375	0,3951627899891499
P4_d1_2.txt	481,8954652734694	25,64949076364394	0,40185426988804307
P4_d1_3.txt	481,8954652734694	22,920223203439875	0,45463726598443743
P4_d1_1.txt	481,8954652734694	25,297612186688582	0,5217770299189989
P2_d3_3.txt	617,8857705360545	21,240547672049725	0,37387839988965943
P2_d3_1.txt	617,8857705360545	21,074386453308158	0,4005846344567684
P2_d3_2.txt	617,8857705360545	21,609427368748246	0,3308164297214184
P3_d2_1.txt	618,1822457034013	23,29832488781953	0,436684929791022
P3_d2_2.txt	618,1822457034013	23,263840652742445	0,3627991169439096
P3_d2_3.txt	618,1822457034013	23,156844720805154	0,4678335287505424
P6_d1_3.txt	634,909877289796	31,57441870019334	0,47540647036383044
P6_d1_1.txt	634,909877289796	32,530308533249794	0,4098835853406528
P6_d1_2.txt	634,909877289796	31,030933223367374	0,4165902138703148
P7_d1_1.txt	808,3663798857143	39,742073344984846	0,4724002631220079
P7_d1_2.txt	808,3663798857143	40,11365813567717	0,5782918777883918
P7_d1_3.txt	808,3663798857143	39,11338945118604	0,5288487589691658
P3_d3_2.txt	911,9951001251701	30,911014032832163	0,47398867676124445
P3_d3_3.txt	911,9951001251701	29,7314402743677	0,6228649467857034
P3_d3_1.txt	911,9951001251701	30,405585270330132	0,4160797524437076
P4_d2_3.txt	918,3949809197279	35,51756971173977	0,5707730854297117
P4_d2_1.txt	918,3949809197279	34,4070302185864	0,6144374765917116
P4_d2_2.txt	918,3949809197279	35,28647009046095	0,5853966106552647
P4_d3_3.txt	1354,8944965659866	47,00306087889179	0,7277145743496743
P4_d3_2.txt	1354,8944965659866	46,232099123620685	0,7903556910078877
P4_d3_1.txt	1354,8944965659866	46,56336854124282	0,7450410018334817

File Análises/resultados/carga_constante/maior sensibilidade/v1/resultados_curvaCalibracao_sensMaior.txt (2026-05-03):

Forca_Equivalente_uN	Deslocamento_script_um	Desvio_Padrao_um
167,19602050612247	2,650227953699916	0,11369586416679983
418,8246331210885	4,888385989627983	0,09344585163820131
618,1822457034013	7,25647498058627	0,08465544417877831
918,3949809197279	11,011556418605776	0,1369748078489766

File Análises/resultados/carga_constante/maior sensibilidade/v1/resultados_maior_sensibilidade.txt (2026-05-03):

Posição do Centro de Gravidade (Y): -0.0672 m (pivô como referencial)
Sensibilidade: 0.0939 m/N
O CG está abaixo do pivô (Equilíbrio Estável).

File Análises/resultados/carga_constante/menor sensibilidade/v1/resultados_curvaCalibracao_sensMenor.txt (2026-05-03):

Forca_Equivalente_uN	Deslocamento_script_um	Desvio_Padrao_um
167,19602050612247	0,47878218626424274	0,055879953376245746
618,1822457034013	1,8185122365609574	0,04539462346158758
911,9951001251701	1,8418879778596315	0,0769171353548244
2272,798227504762	6,690188939643546	0,054465380402743145

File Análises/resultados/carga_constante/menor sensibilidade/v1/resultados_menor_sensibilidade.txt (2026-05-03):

Posição do Centro de Gravidade (Y): -0.3369 m (pivô como referencial)
Sensibilidade: 0.0179 m/N
O CG está abaixo do pivô (Equilíbrio Estável).

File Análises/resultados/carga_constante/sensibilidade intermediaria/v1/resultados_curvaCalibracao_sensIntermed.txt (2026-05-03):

Forca_Equivalente_uN	Deslocamento_script_um	Desvio_Padrao_um
167,19602050612247	1,5257615127211728	0,0847188425542229
167,19602050612247	1,423237273916354	0,10081185710970245
219,76349570612243	2,185506640054078	0,057896090001982654
219,76349570612243	1,9977216844821206	0,09998581312962104
324,3693912816326	2,9960000375033786	0,07785437182987949
324,3693912816326	2,401573254417534	0,06568608605840764
470,08736200272114	3,5189739630420265	0,12415216248666912
470,08736200272114	3,128133765737345	0,1001355470794617
481,8954652734694	4,728323381513613	0,09218229028524261
481,8954652734694	5,847511926572043	0,5436711886457491
486,3336474122449	5,0236660193102765	0,08652542680489857
486,3336474122449	4,471582365708118	0,06322730074100216
634,909877289796	5,803216918252013	0,0589699351167432
634,909877289796	6,101860402085155	0,18148414246878633
808,3663798857143	7,651419551723982	0,10690424291529421
808,3663798857143	7,245674717473794	0,10894271299596024
911,9951001251701	5,871157888343973	0,0955963767657098
911,9951001251701	5,362589192377063	0,1448660306277207

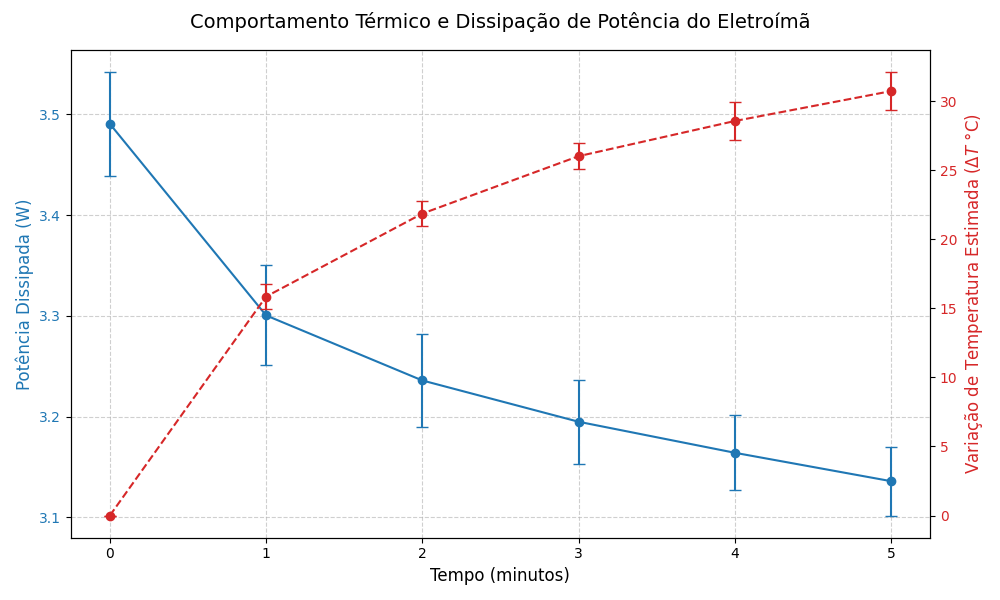
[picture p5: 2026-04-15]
Análises/resultados/eletroima-efeito_joule/eletroima_temperatura_potencia.png

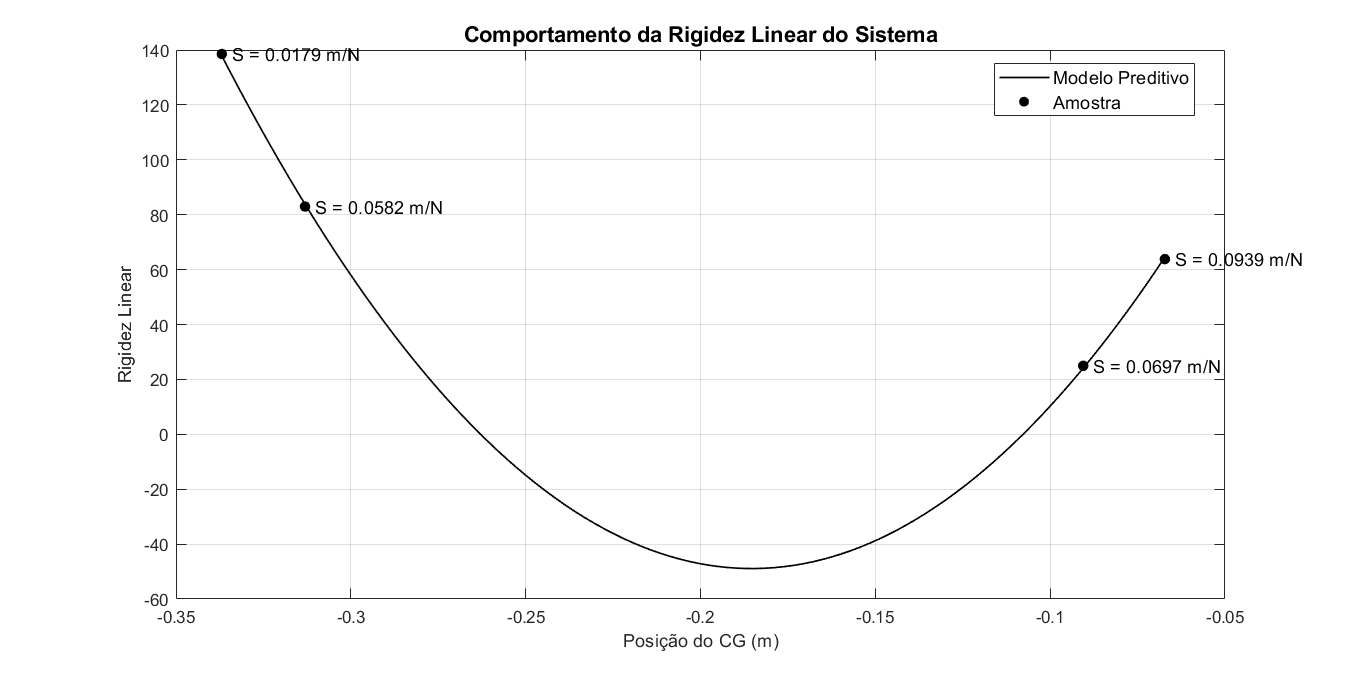
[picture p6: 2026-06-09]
Análises/resultados/carga_constante/comportamento_offset_sensibilidade_geral.png

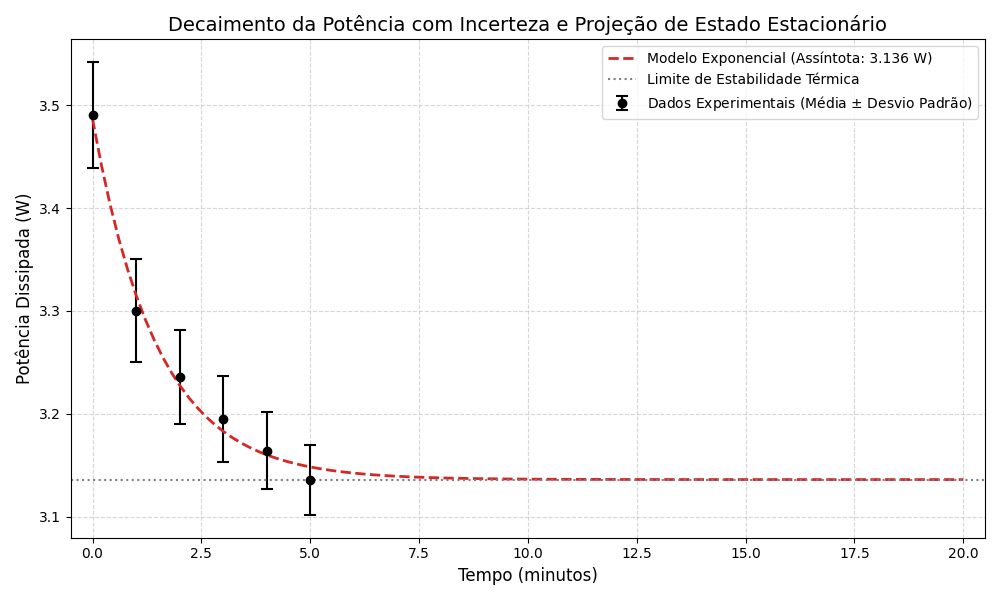
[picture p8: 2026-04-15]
Análises/resultados/eletroima-efeito_joule/eletroima_potencia_decaimento.png

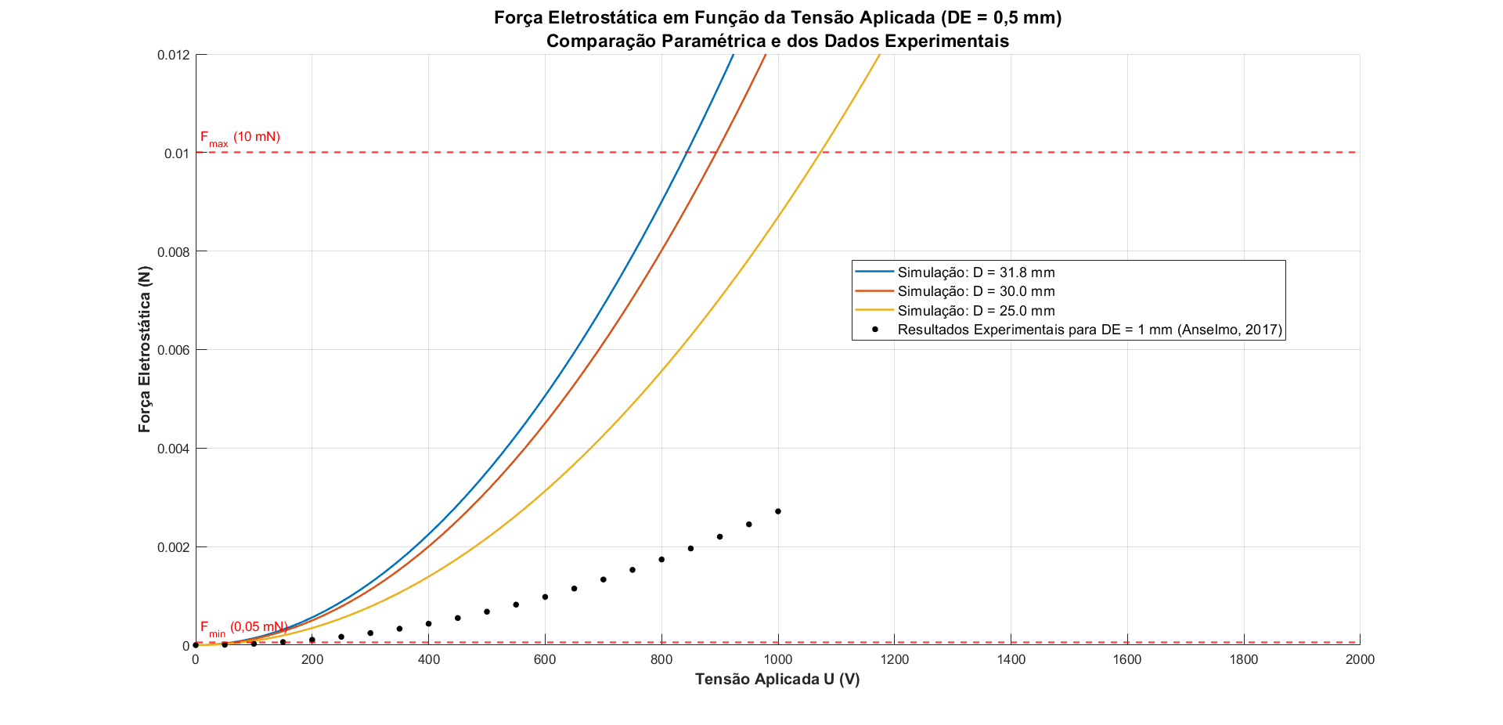
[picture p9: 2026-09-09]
Análises/resultados/DCE-dimensionamento/FE_dif_diametros_DE05mm.png

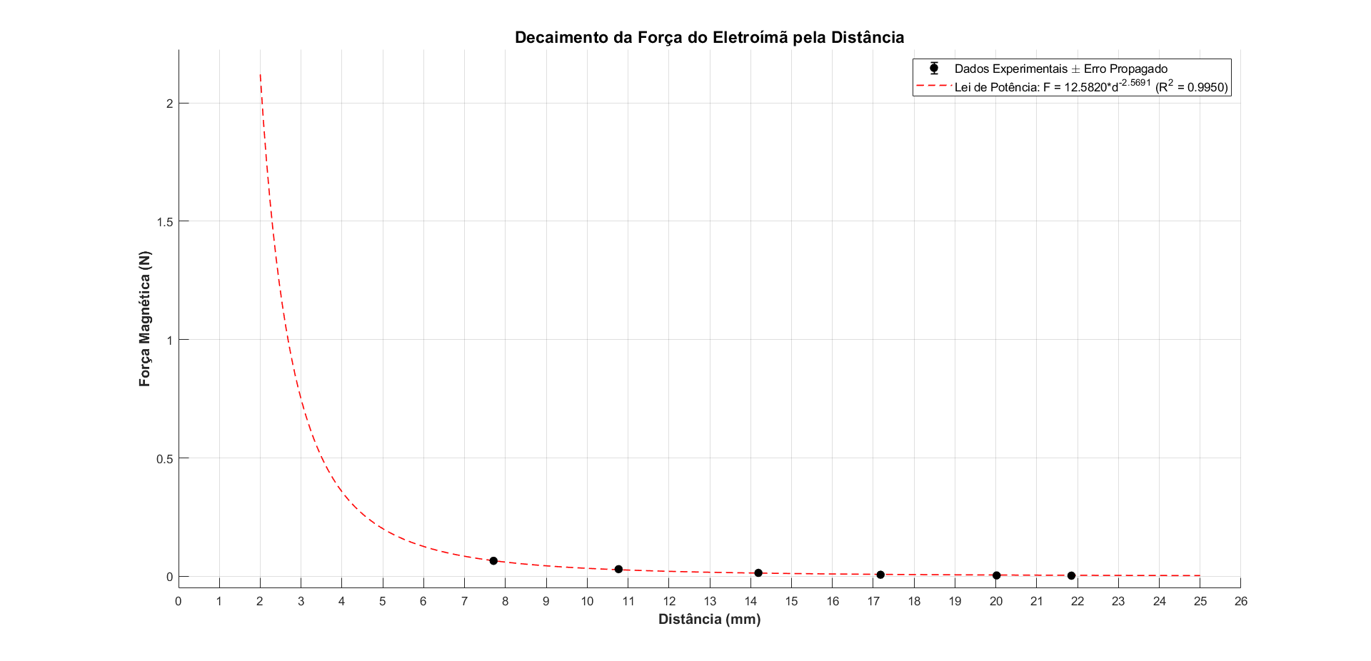
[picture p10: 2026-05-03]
Análises/resultados/eletroima-forca/forca-vs-deslocamento-eletroima-LaSE.png

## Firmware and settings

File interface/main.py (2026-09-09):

# -*- coding: utf-8 -*-
"""
LaSE — Balança de Microempuxo para Pequenos Satélites
Sistema de Controle e Aquisição de Dados
INPE / LaSE
"""

import streamlit as st
import pandas as pd
import numpy as np
import matplotlib.pyplot as plt
import matplotlib.gridspec as gridspec
import math
import io
import os
import time
import serial.tools.list_ports
from datetime import datetime

# ── Importa módulos do projeto ──────────────────────────────────────────────
import sys, os
_here = os.path.dirname(os.path.abspath(__file__))
sys.path.insert(0, _here)
sys.path.insert(0, os.path.join(_here, '..', 'signal_processing'))
sys.path.insert(0, os.path.join(_here, '..', 'calibration'))
sys.path.insert(0, os.path.join(_here, '..', 'tools'))
from processing import apply_lowpass_filter, convert_to_mn, calculate_metrics
from report_pdf import gerar_pdf
from find_deflection import calcular_deflexao as _calcular_deflexao_mod
from k_calculation import calibracao_estatica as _calibracao_estatica_mod
from fn_calculation import calcular_fnat as _calcular_fnat_mod
from LVDT_Plot_V2 import detectar_xmax as _detectar_xmax_mod

# ── Configuração da página ───────────────────────────────────────────────────
st.set_page_config(
    page_title="LaSE — Balança de Microempuxo",
    page_icon=None,
    layout="wide",
    initial_sidebar_state="expanded"
)

# ── Estilo global ─────────────────────────────────────────────────────────────
st.markdown("""
<style>
    .block-container { padding-top: 1.5rem; }
    .stMetric { background: #f8f9fb; border: 1px solid #e2e6ef; border-radius: 8px; padding: 12px; }
    .stAlert  { border-radius: 8px; }
    .stAlert p { margin: 0; }
    div[data-testid="stMetricValue"] { font-size: 1.4rem; font-weight: 600; }
    .req-badge {
        display: inline-block; font-size: 10px; font-weight: 600;
        padding: 1px 6px; border-radius: 10px; margin-left: 4px;
        background: #fef2f2; color: #991b1b; border: 1px solid #fecaca;
    }
    .section-title { font-size: 13px; font-weight: 600; color: #4a5568;
        text-transform: uppercase; letter-spacing: .05em; margin-bottom: 8px; }
    .stDownloadButton button { font-weight: 500; }
</style>
""", unsafe_allow_html=True)


# ════════════════════════════════════════════════════════════════════════════
# FUNÇÕES AUXILIARES — DSP
# ════════════════════════════════════════════════════════════════════════════

def calcular_fs(time_arr):
    """Calcula frequência de amostragem a partir do vetor de tempo."""
    if len(time_arr) < 2:
        return 50.0
    return (len(time_arr) - 1) / (time_arr[-1] - time_arr[0])


def calcular_fnat(d_um, fs, cutoff=0.5, max_freq=5.0):
    """
    FFT com remoção de offset — retorna (fnat, freqs, magnitudes_raw, magnitudes_filt).
    Delegado a signal_processing/fn_calculation.py (módulo canônico da Camada 1).
    """
    return _calcular_fnat_mod(d_um, fs, cutoff=cutoff, max_freq=max_freq)


def calcular_deflexao(time_arr, d_um, t1_start, t1_end, t2_start, t2_end, fs, cutoff=0.05):
    """
    Calcula deflexão entre baseline e patamar com incerteza.
    Delegado a calibration/find_deflection.py (módulo canônico da Camada 3).
    """
    return _calcular_deflexao_mod(time_arr, d_um, t1_start, t1_end, t2_start, t2_end,
                                   fs, cutoff=cutoff)


def detectar_xmax(d_um, fs, cutoff=0.1):
    """
    Identifica xmax (maior deflexão absoluta) no sinal filtrado.
    Delegado a tools/LVDT_Plot_V2.py (módulo canônico de identificação de pico).
    """
    return _detectar_xmax_mod(d_um, fs, cutoff=cutoff)


def calibracao_estatica(massas_kg, desl_m, erros_m, g=9.81, l_aplicacao=0.005, L_lvdt=0.3):
    """
    Regressão linear T(θ) = k·θ + a para determinar a rigidez torcional k.
    Delegado a calibration/k_calculation.py (módulo canônico da Camada 3).
    """
    return _calibracao_estatica_mod(massas_kg, desl_m, erros_m, g=g,
                                     l_aplicacao=l_aplicacao, L_lvdt=L_lvdt)


def calcular_parametros_balanca(m1_kg, r1_m, m2_kg, r2_m, m_balanca=0.8, r_balanca=0.06, g=9.81):
    """Calcula CG, I, k, fnat e sensibilidade a partir dos contrapesos."""
    m_tot = m1_kg + m2_kg + m_balanca
    cg = -(m1_kg * r1_m + m2_kg * r2_m) / m_tot  # negativo = abaixo do pivô
    I  = m1_kg * r1_m**2 + m2_kg * r2_m**2 + m_balanca * r_balanca**2
    k  = m_tot * g * abs(cg)
    fn = (1 / (2 * np.pi)) * np.sqrt(k / I) if I > 0 and k > 0 else 0.0
    S  = (1 / (m_tot * (2 * np.pi * fn)**2)) * 1e6 if fn > 0 else 0.0
    return {"cg": cg, "I": I, "k": k, "fn": fn, "S": S, "m_tot": m_tot}


def calcular_voltagem_dce(forca_uN, de_mm, k_dce=0.45):
    """Calcula voltagem DCE necessária. Retorna V e flag de bloqueio (RF14)."""
    V = math.sqrt(forca_uN / k_dce) * de_mm
    bloqueado = V > 1000.0
    return round(V, 1), bloqueado


def gerar_csv(time_arr, thrust_mn):
    df = pd.DataFrame({"Tempo (s)": time_arr, "Empuxo (mN)": thrust_mn})
    return df.to_csv(index=False).encode("utf-8")


def gerar_simulacao(modo="pulsado", duracao=30, fs=100):
    """Gera sinal simulado de pêndulo amortecido para testes sem hardware."""
    t = np.linspace(0, duracao, int(duracao * fs))
    fn_sim, zeta = 1.2, 0.05
    wd = fn_sim * np.sqrt(1 - zeta**2)
    ruido = np.random.normal(0, 0.3, len(t))

    if modo == "pulsado":
        sinal = np.zeros(len(t))
        for pulso_t in [5, 12, 19, 26]:
            t_rel = t - pulso_t
            mask = t_rel >= 0
            sinal[mask] += (
                8.0 * np.exp(-zeta * 2 * np.pi * fn_sim * t_rel[mask])
                * np.sin(2 * np.pi * wd * t_rel[mask])
            )
    else:
        sinal = np.where(
            (t > 5) & (t < 25),
            5.0 + 0.3 * np.sin(2 * np.pi * fn_sim * t),
            0.1 * np.sin(2 * np.pi * fn_sim * t)
        )

    return pd.DataFrame({"time": t, "raw_disp": sinal + ruido})


def listar_portas():
    return [p.device for p in serial.tools.list_ports.comports()] or ["Nenhuma porta detectada"]


# ════════════════════════════════════════════════════════════════════════════
# PERSISTÊNCIA DE CALIBRAÇÃO
# ════════════════════════════════════════════════════════════════════════════

import json

_CALIB_FILE = os.path.join(os.path.dirname(os.path.abspath(__file__)), "calibration_state.json")

_CALIB_KEYS = [
    "calibrado", "k_torque", "l_lvdt", "l_thrust",
    "fn_calculada", "S_calculada", "modo_teste",
    "timestamp_calib", "massa_calib", "cg_calib",
]


def save_calibration():
    data = {k: st.session_state[k] for k in _CALIB_KEYS}
    with open(_CALIB_FILE, "w", encoding="utf-8") as f:
        json.dump(data, f, indent=2)


def load_calibration():
    if not os.path.exists(_CALIB_FILE):
        return
    try:
        with open(_CALIB_FILE, encoding="utf-8") as f:
            data = json.load(f)
        for k in _CALIB_KEYS:
            if k in data:
                st.session_state[k] = data[k]
    except Exception:
        pass


def clear_calibration():
    if os.path.exists(_CALIB_FILE):
        os.remove(_CALIB_FILE)
    for k in _CALIB_KEYS:
        st.session_state.pop(k, None)


# ════════════════════════════════════════════════════════════════════════════
# ESTADO DA SESSÃO
# ════════════════════════════════════════════════════════════════════════════

defaults = {
    "calibrado": False,
    "k_torque": 0.0125,
    "l_lvdt": 0.3,
    "l_thrust": 0.25,
    "fn_calculada": None,
    "S_calculada": None,
    "df_dados": None,
    "modo_teste": "pulsado",
    "timestamp_calib": None,
    "massa_calib": 0.0,
    "cg_calib": 0.0,
    "_calib_loaded": False,
}
for k, v in defaults.items():
    if k not in st.session_state:
        st.session_state[k] = v

if not st.session_state["_calib_loaded"]:
    load_calibration()
    st.session_state["_calib_loaded"] = True


# ════════════════════════════════════════════════════════════════════════════
# NAVEGAÇÃO
# ════════════════════════════════════════════════════════════════════════════

st.markdown("### LaSE — Balança de Microempuxo")

status_calib = "Calibrada" if st.session_state.calibrado else "Não calibrada"
cor_status   = "green" if st.session_state.calibrado else "orange"
st.markdown(
    f"<span style='font-size:12px;color:{cor_status};font-weight:600;'>{status_calib}</span> &nbsp;|&nbsp; "
    f"<span style='font-size:12px;color:#9aa3b5;'>{datetime.now().strftime('%d/%m/%Y %H:%M')}</span>",
    unsafe_allow_html=True
)

aba1, aba2, aba3 = st.tabs([
    "1 · Calibração",
    "2 · Aquisição de dados",
    "3 · Análise e exportação"
])


# ════════════════════════════════════════════════════════════════════════════
# ABA 1 — CALIBRAÇÃO
# ════════════════════════════════════════════════════════════════════════════

with aba1:

    st.markdown("#### Configuração da balança")
    st.caption("Preencha os parâmetros físicos da balança antes de iniciar qualquer teste.")

    col_cp, col_res, col_dce = st.columns(3)

    # ── Contrapesos ──────────────────────────────────────────────────────────
    with col_cp:
        st.markdown('<div class="section-title">Contrapesos <span class="req-badge">RF03 · RF11</span></div>',
                    unsafe_allow_html=True)

        cp1_on = st.checkbox("Contrapeso 1 ativo", value=True)
        with st.container():
            cp1_m = st.number_input("Massa CP1 (g)",  value=50.0,  step=1.0,  format="%.1f",
                                    disabled=not cp1_on, key="cp1m")
            cp1_r = st.number_input("Distância CP1 ao pivô (mm)", value=120.0, step=1.0, format="%.1f",
                                    disabled=not cp1_on, key="cp1r")

        cp2_on = st.checkbox("Contrapeso 2 ativo", value=False)
        with st.container():
            cp2_m = st.number_input("Massa CP2 (g)",  value=20.0,  step=1.0,  format="%.1f",
                                    disabled=not cp2_on, key="cp2m")
            cp2_r = st.number_input("Distância CP2 ao pivô (mm)", value=80.0,  step=1.0, format="%.1f",
                                    disabled=not cp2_on, key="cp2r")

        cg_manual = st.checkbox("Inserir CG manualmente")
        if cg_manual:
            cg_valor = st.number_input("CG eixo y (m)", value=-0.010, step=0.001, format="%.4f")
        else:
            cg_valor = None

        st.markdown('<div class="section-title" style="margin-top:12px;">Braços da balança</div>',
                    unsafe_allow_html=True)
        l_lvdt   = st.number_input("Braço LVDT — pivô ao sensor (m)",    value=0.300, step=0.001, format="%.3f")
        l_thrust = st.number_input("Braço motor — pivô ao propulsor (m)", value=0.250, step=0.001, format="%.3f")

    # ── Parâmetros calculados ─────────────────────────────────────────────
    with col_res:
        st.markdown('<div class="section-title">Parâmetros calculados</div>', unsafe_allow_html=True)

        m1 = (cp1_m / 1000) if cp1_on else 0.0
        r1 = (cp1_r / 1000) if cp1_on else 0.0
        m2 = (cp2_m / 1000) if cp2_on else 0.0
        r2 = (cp2_r / 1000) if cp2_on else 0.0

        params = calcular_parametros_balanca(m1, r1, m2, r2)
        cg_final = cg_valor if cg_manual else params["cg"]

        if cg_final > 0.001:
            st.error("**CG acima do pivô — balança instável.**  \n"
                     "Reposicione os contrapesos para que o CG fique abaixo do ponto de pivô.")
        elif params["fn"] > 0 and params["fn"] < 0.5:
            st.warning(f"Frequência natural muito baixa ({params['fn']:.3f} Hz).  \n"
                       "Aproxime os contrapesos do pivô ou reduza a massa para aumentar fnat.")
        elif params["fn"] > 5:
            st.warning(f"Frequência natural muito alta ({params['fn']:.3f} Hz).  \n"
                       "Afaste os contrapesos do pivô ou aumente a massa.")
        elif params["fn"] > 0:
            st.success("Parâmetros dentro do intervalo operacional.")

        mc1, mc2 = st.columns(2)
        mc1.metric("CG calculado",    f"{cg_final:.4f} m",      help="Negativo = CG abaixo do pivô (estável)")
        mc2.metric("Inércia I",        f"{params['I']:.5f} kg·m²")
        mc1.metric("Rigidez k",        f"{params['k']:.4f} N·m/rad")
        mc2.metric("Freq. natural fnat", f"{params['fn']:.3f} Hz",  help="Ideal: 0.5 – 5 Hz")
        mc1.metric("Sensibilidade S",  f"{params['S']:.2f} µm/N",  help="Quanto a balança se desloca por Newton")

        st.markdown('<div class="section-title" style="margin-top:12px;">Constante k — calibração estática <span class="req-badge">RF15</span></div>',
                    unsafe_allow_html=True)
        st.caption("Carregue um CSV com colunas M (kg), d (m), e (m) para calcular k por regressão linear.")

        arquivo_k = st.file_uploader("Arquivo de calibração estática (.csv)", type=["csv"], key="calib_k")
        if arquivo_k:
            try:
                df_k = pd.read_csv(arquivo_k)
                k_calc, a_off, r2, Theta, Mteq, err_theta = calibracao_estatica(
                    df_k["M"].values, df_k["d"].values, df_k["e"].values,
                    l_aplicacao=l_thrust, L_lvdt=l_lvdt
                )
                cc1, cc2 = st.columns(2)
                cc1.metric("k calculado", f"{k_calc:.5f} N·m/rad")
                cc2.metric("R²",          f"{r2:.4f}", delta="válido" if r2 >= 0.99 else "abaixo de 0.99")

                if r2 >= 0.99:
                    st.success("Ajuste linear válido — R² ≥ 0.99.")
                else:
                    st.warning("R² abaixo de 0.99. Revise os dados de calibração.")

                fig_k, ax_k = plt.subplots(figsize=(5, 3))
                ax_k.errorbar(Theta, Mteq, xerr=err_theta, fmt="o", color="#2563eb", label="Dados", markersize=4)
                x_fit = np.linspace(Theta.min(), Theta.max(), 100)
                ax_k.plot(x_fit, a_off + k_calc * x_fit, "--", color="#16a34a",
                          label=f"k = {k_calc:.4f} N·m/rad")
                ax_k.set_xlabel("θ (rad)"); ax_k.set_ylabel("Torque (N·m)")
                ax_k.set_title(f"Curva de calibração — R² = {r2:.4f}")
                ax_k.legend(fontsize=8); ax_k.grid(alpha=0.3)
                plt.tight_layout()
                st.pyplot(fig_k)

                if st.button("Usar este k na análise"):
                    st.session_state.k_torque = k_calc
                    st.success(f"k = {k_calc:.5f} N·m/rad salvo na sessão.")
            except Exception as e:
                st.error(f"Erro ao processar arquivo: {e}")

    # ── DCE ──────────────────────────────────────────────────────────────────
    with col_dce:
        st.markdown('<div class="section-title">Configuração DCE <span class="req-badge">RF05 · RF06 · RF14</span></div>',
                    unsafe_allow_html=True)

        modo_dce = st.radio("Tipo de teste", ["Pulsado (Ibit)", "Contínuo (ss)"],
                            horizontal=True, key="modo_dce_radio")

        if "Pulsado" in modo_dce:
            st.info("**Modo pulsado:** o sistema vai capturar a maior deflexão (xmax) gerada "
                    "pelo impulso. Use para caracterizar PPTs e propulsores pulsados.")
        else:
            st.info("**Modo contínuo:** aguarda regime permanente (variação <0.1%) e mede a "
                    "deflexão estável (xss). Filtro Butterworth ativo.")

        forca_uN = st.slider("Força desejada (µN)", min_value=10, max_value=1000,
                             value=100, step=1, key="forca_slider")
        forca_num = st.number_input("Ou digite a força (µN)", value=float(forca_uN),
                                    min_value=10.0, max_value=1000.0, step=1.0, key="forca_num")
        forca_final = forca_num

        de_mm = st.number_input("Distância entre placas DCE — DE (mm)",
                                value=1.00, min_value=0.50, max_value=2.00, step=0.01, format="%.2f")
        st.caption("Dados experimentais disponíveis para: 1.00 mm e 0.99 mm. Outros valores: estimado (erro ≤2%).")

        V_calc, bloqueado = calcular_voltagem_dce(forca_final, de_mm)

        st.markdown("**Voltagem calculada para o DCE:**")
        if bloqueado:
            st.error(f"**{V_calc} V — BLOQUEADO** — RF14: limite de 1.000 V atingido. "
                     "Reduza a força ou aumente DE.")
        elif V_calc > 800:
            st.warning(f"**{V_calc} V** — acima de 80% do limite. Monitore com cuidado.")
        else:
            st.success(f"**{V_calc} V** — dentro do limite de segurança (≤ 1.000 V)  —  {V_calc/10:.1f}% do limite")

        pct_volt = min(V_calc / 1000 * 100, 100)
        st.progress(int(pct_volt))
        st.caption(f"0 V ────────── 500 V ────────── 1.000 V (limite)")

        with st.expander("Parâmetros de análise do regime"):
            if "Pulsado" in modo_dce:
                st.markdown("""
                | Parâmetro | Valor |
                |-----------|-------|
                | Medida de interesse | xmax (1º pico) |
                | Resolução | 0.01 µm |
                | Repetições | N = 10 |
                | Filtro | Butterworth 5ª ord. |
                """)
            else:
                st.markdown("""
                | Parâmetro | Valor |
                |-----------|-------|
                | Medida de interesse | x_ss (regime perm.) |
                | Settling time | ~100 s (τ × 4) |
                | Critério steady-state | variação < 0.1% |
                | Filtro | Butterworth 5ª ord. |
                """)

    st.markdown("---")

    # ── Sequência de calibração ──────────────────────────────────────────────
    st.markdown("#### Sequência de calibração automática")
    st.caption("Execute as etapas em ordem. Tempo estimado: < 30 minutos.")

    seq_col1, seq_col2 = st.columns([3, 1])
    with seq_col1:
        etapa = st.selectbox("Etapa atual", [
            "1 · Calibração estática — deflexão com massa padrão",
            "2 · Calibração dinâmica — FFT e frequência natural",
            "3 · Validação DCE — curvas FE e tabela lookup",
            "4 · Aprovação final — verificação de incerteza"
        ])
    with seq_col2:
        st.markdown("<br>", unsafe_allow_html=True)
        if st.button("Marcar etapa como concluída", use_container_width=True):
            if "4 ·" in etapa:
                st.session_state.calibrado = True
                st.session_state.k_torque = params["k"] if not arquivo_k else st.session_state.k_torque
                st.session_state.l_lvdt   = l_lvdt
                st.session_state.l_thrust = l_thrust
                st.session_state.fn_calculada = params["fn"]
                st.session_state.S_calculada  = params["S"]
                st.session_state.timestamp_calib = datetime.now().strftime("%d/%m/%Y %H:%M")
                st.session_state.massa_calib = params["m_tot"]
                st.session_state.cg_calib    = cg_final
                st.session_state.modo_teste  = "pulsado" if "Pulsado" in modo_dce else "continuo"
                save_calibration()
                st.success("Calibração concluída. A balança está pronta para uso.")
                st.balloons()
            else:
                st.info(f"Etapa marcada: {etapa[:30]}…  \nProssiga para a próxima etapa.")

    if st.session_state.calibrado:
        cb1, cb2 = st.columns([5, 1])
        cb1.success(f"Balança calibrada em {st.session_state.timestamp_calib}  —  "
                    f"k = {st.session_state.k_torque:.5f} N·m/rad  |  "
                    f"fnat = {st.session_state.fn_calculada:.3f} Hz")
        if cb2.button("Limpar calibração", use_container_width=True):
            clear_calibration()
            st.rerun()


# ════════════════════════════════════════════════════════════════════════════
# ABA 2 — AQUISIÇÃO DE DADOS
# ════════════════════════════════════════════════════════════════════════════
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

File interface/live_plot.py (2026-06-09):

# -*- coding: utf-8 -*-
"""
Live Plotter - Monitoramento em Tempo Real (DSP)
Objetivo: Transformar deslocamento (µm) em Empuxo (mN) em tempo real.
"""
import sys
import os

# 1. Ajuste do Backend Gráfico
try:
    import matplotlib
    matplotlib.use('Qt5Agg') 
except:
    try:
        matplotlib.use('TkAgg')
    except:
        pass

# 2. Configuração de Caminhos
current_dir = os.path.dirname(os.path.abspath(__file__))
src_dir = os.path.abspath(os.path.join(current_dir, '..'))
if src_dir not in sys.path:
    sys.path.append(src_dir)

import pandas as pd
import matplotlib.pyplot as plt
from matplotlib.animation import FuncAnimation
from time import sleep
import numpy as np
from processing import apply_lowpass_filter 

# 3. Constantes de Calibração (Ajuste conforme sua bancada física)
K_TORQUE = 0.0125  # Constante elástica k (Nm/rad)
L_LVDT = 0.3       # Distância do LVDT ao pivô (m)
L_THRUST = 0.25    # Distância do Propulsor ao pivô (m)

# Definição do Arquivo de Dados
filename = os.path.abspath(os.path.join(current_dir, '..', 'Análises', 'data', 'carga_constante', 'P1_d1_4.txt'))

windowsize = 20 
Ns = 200        

print(f"Buscando dados em: {filename}")

# --- 1. ESPERA PELO ARQUIVO ---
while True:
    if os.path.isfile(filename) and os.path.getsize(filename) > 0:
        break
    print("Aguardando arquivo de dados...")
    sleep(0.5)

# --- 2. CÁLCULO INICIAL DE FREQUÊNCIA E OFFSET ---
while True:
    try:
        data = pd.read_csv(filename, sep="\t", header=None, decimal=',')
        Nb = len(data) - 1
        if Nb >= Ns:
            total_t = data[0].iloc[Nb-1] - data[0].iloc[0]
            sf = Nb / total_t
            print(f'Sampling frequency detectada: {sf:.2f} Hz')
            
            N = int(windowsize * sf) 
            av1 = np.average(data[1].iloc[:Ns] * 1000) 
            break
    except Exception as e:
        print(f"Erro na leitura inicial: {e}")
    sleep(0.5)

# --- 3. FUNÇÃO DE ANIMAÇÃO ---
def animate(i):
    try:
        data = pd.read_csv(filename, sep="\t", header=None, decimal=',')
        data_window = data.tail(N)
        
        time = data_window[0].values
        d_raw = data_window[1].values * 1000 # µm
        
        # Filtro Butterworth (0.3 Hz para manter dinâmica visível)
        if len(d_raw) > 30:
            d_filtered = apply_lowpass_filter(d_raw, fs=sf, cutoff_freq=0.5)
        else:
            d_filtered = d_raw - av1

        # --- CÁLCULO DSP: CONVERSÃO PARA EMPUXO (mN) ---
        # 1. Ângulo em radianos (d em metros / L em metros)
        theta = (d_filtered / 1e6) / L_LVDT 
        # 2. Torque (k * theta)
        torque = K_TORQUE * theta
        # 3. Força em milli-Newtons (Torque / L_thrust * 1000)
        thrust_mN = (torque / L_THRUST) * 1000

        plt.cla()
        # Plota o sinal de Empuxo em verde (padrão para força)
        plt.plot(time, thrust_mN, color='green', linewidth=1.5, label='Thrust Signal (mN)')
        
        plt.xlabel("Time (s)")
        plt.ylabel("Thrust (mN)")
        plt.title("Real-Time Thrust Monitoring (mN)")
        plt.grid(True, alpha=0.3)
        plt.legend(loc='upper right')
        
        if len(thrust_mN) > 0:
            plt.ylim(np.min(thrust_mN) - 0.05, np.max(thrust_mN) + 0.05)
            
    except Exception:
        pass

# --- 4. EXECUÇÃO ---
fig = plt.figure()
ani = FuncAnimation(fig, animate, interval=50, cache_frame_data=False)
plt.tight_layout()
plt.show()

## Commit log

2026-04-15 Add analysis scripts for vibration and calibration studies
    [data.csv]
2026-04-18 analise de coletas feitas no dia 17 de abril - modos de vibração
2026-04-23 Atualização script carga_constante e inclusão de gráficos (erro no calculo de rigidez - massa não aplicada corretamente)
2026-04-24 Add calibration analysis script for force equivalent vs displacement
    - Implemented a Python script to perform linear regression on experimental data.
    - Included error bars for data points and plotted the fitted line.
    - Configured visual elements such as labels, title, grid, and legend.
    - Printed calculated stiffness and offset values to the terminal.
2026-04-24 Add scripts for thermal drift correction and magnetic force analysis
    - Implemented carga_constante_derivaTermica.m for analyzing thermal drift in displacement measurements, including data import, processing, and uncertainty calculations.
    - Created forca_eletroima.m to analyze magnetic force versus distance using power law fitting, including error propagation and graphical representation of results.
    - Both scripts include functionality for saving output figures and displaying results in the console.
2026-05-03 Atualizações de códigos e resultados de calibração
2026-05-06 Comment out save and print statements in calibration curve plotting function
2026-05-18 - inclusão de novos dados coletados no dia 08 de maio; - melhoria no script "graph_calibracao" para gerar área de confiança em função do coeficiente de determinação R^2 - novos graficos de calibração
2026-05-22 - inclusão do CAD para edição da posição do contrapeso e identificação do CG de forma simplificada; - atualização do código que calcula sensibilidade para inserir diretamente o CG - melhoria nos códi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
    [0.Thrust_Balance_cg_y.SLDASM, 0.Thrust_Balance_cg_y.x_t, Blade_Spring-1.SLDPRT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]
2026-06-09 - inclusão de novos dados de calibração - melhoria dos scripts de calibração
    [0.Thrust_Balance_cg_y.SLDASM, CW_MAIOR.SLDPRT, TB_Base-1.SLDASM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]
2026-06-15 Atualização de curvas de calibração - CG e sensibilidades errados - CG corrigido conforme SOLIDWORKS
2026-06-17 Inclusão de roteiro de experimentação para os testes do DCE.
2026-06-17 Atualização do range de forças: 0,5 até 100 mN
2026-06-22 Atualização do relatório de experimento do DCE
2026-06-22 Aualizações DCE_calculos - comparacoes entre os resultados analiticos e experimentais do INPE + grafico de erro relativo
2026-09-09 Corrige geração de PDF quebrada e elimina duplicação entre módulos e main.py
    report_pdf.py tinha uma IndentationError (trecho do Streamlit colado dentro
    de gerar_pdf()) que impedia o módulo de ser importado; o botão "Gerar PDF"
    em main.py ficava desabilitado apontando para um backend FastAPI inexistente.
    Corrigido e conectado de ponta a ponta (testado no navegador).
    find_deflection.py, k_calculation.py, fn_calculation.py e LVDT_Plot_V2.py
    eram scripts standalone com caminhos hardcoded, nunca importados — main.py
    mantinha cópias próprias de cada função. Agora são módulos importáveis e
    main.py delega para eles (equivalência numérica verificada), alinhando o
    código com a arq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
    [main.py, report_pdf.py]
2026-09-09 Remove pasta .claude do controle de versão
    Configuração local do Claude Code, não deve fazer parte do repositório.
2026-09-09 Adiciona guia de módulos ao README
    Descreve o que cada arquivo da arquitetura viva (calibration/,
    signal_processing/, interface/, hardware/, tools/) faz e como se
    encaixa no pipeline, para facilitar onboarding de quem abrir o repo.
2026-09-14 Adiciona rotina de calibração in situ via DCE (simulada, sem hardware validado)
    hardware/dce_power_supply.py: driver SCPI/USB da fonte RIGOL DP932U
    (RigolDP932U) e um substituto sem hardware (FontePowerSupplySimulada) com a
    mesma interface.
    calibration/dce_calibration.py: calibrar_via_dce() varre voltagens no DCE,
    lê a deflexão resultante e ajusta a rigidez torcional (kappa) por regressão,
    reaproveitando o modelo de k_calculation.py com força eletrostática no lugar
    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
2026-09-14 Corrige bug de unidades na calibração via DCE e documenta módulos novos no README
    forca_dce() retornava força em µN mas era tratada como N no cálculo de
    torque, inflando os resultados em 1e6x. Corrigido com a conversão explícita
    (mesma convenção de unidades já usada em interface/main.py).
    README: adiciona dce_calibration.py e dce_power_supply.py à árvore e ao
    Guia de Módulos, e corrige a última menção a "rigidez torcional" para
    "rigidez efetiva" (consistente com a correção de terminologia aplicada
    no artigo do IAC).
2026-09-14 Varia a estrutura do Guia de Módulos no README
    As entradas seguiam todas o mesmo molde rígido (nome — descrição —
    função() — importado por). Reescrito em prosa mais natural, agrupando
    os dois módulos de rigidez efetiva (massa vs. DCE) numa explicação só.
2026-09-14 Adiciona screenshot da interface ao README
    Captura da aba de Calibração do app Streamlit rodando, pra dar uma
    visão rápida do produto pra quem abre o repositório pela primeira vez.
2026-09-14 Remove menção à AEB do README
    O LaSE não tem parceria com a Agência Espacial Brasileira -- o trabalho
    é só do Laboratório de Sistemas Espaciais (LaSE/UnB).
2026-09-14 Troca licença de MIT para PolyForm Noncommercial 1.0.0
    MIT permitia uso comercial por terceiros sem envolvimento do LaSE. PolyForm
    Noncommercial mantém o código aberto para pesquisa, ensino e outras
    organizações sem fins lucrativos, mas bloqueia exploração comercial direta
    sem licenciamento separado.

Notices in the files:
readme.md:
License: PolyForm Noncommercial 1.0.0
